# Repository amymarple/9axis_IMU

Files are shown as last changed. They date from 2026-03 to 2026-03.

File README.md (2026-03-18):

# 9-Axis IMU Intan Sync Toolbox

Author: Hongyu Chang
Date: 2026/03/01

This repository is organized as a small toolbox for collecting 9-axis IMU data with an Arduino Mega, sending a TTL sync pulse to an Intan system, and logging the IMU stream to a computer with Python.

The active toolbox now has one supported Arduino sketch and one supported Python logger:

- `arduino/imu_intan_sync_toolbox/imu_intan_sync_toolbox.ino`
- `python/read_imu.py`

Legacy experiments that are not part of the supported workflow are kept under `archive/`.

## Folder Layout

- `arduino/imu_intan_sync_toolbox/`
  Arduino sketch for the MPU9250 + Intan TTL sync workflow.
- `python/read_imu.py`
  Python logger that starts the Arduino stream, reads binary packets, and saves a CSV file.
- `python/requirements.txt`
  Python dependency list.
- `3D_printing_parts/`
  3D design files for mounting the IMU as part of an electrophysiology headstage assembly.
- `archive/`
  Older notebook, legacy Arduino sketches, legacy Python logger, and unrelated servo test material.

## Hardware

This toolbox assumes:

- Arduino Mega
- MPU9250 IMU
- Intan digital input for the sync pulse

Default wiring for the Arduino Mega:

- `MPU9250 VCC -> 3.3V`
- `MPU9250 GND -> GND`
- `MPU9250 SDA -> pin 20`
- `MPU9250 SCL -> pin 21`
- `Arduino pin 13 -> Intan digital input`
- `Arduino GND -> Intan GND`

Important:

- Verify your Intan digital input voltage compatibility before directly wiring the Arduino sync pin.
- Use a level shifter if your recording setup requires it.
- A shared ground between Arduino and Intan is required for reliable TTL synchronization.

Reference for the Arduino-side IMU implementation:

- based on `hideakitai/MPU9250`
- based on `arnefmeyer/IMUReaderPlugin`
- https://github.com/hideakitai/MPU9250.git
- https://github.com/arnefmeyer/IMUReaderPlugin.git

## 3D Printing Parts

The folder `3D_printing_parts/` contains the mechanical design files for incorporating the IMU into the ephys headstage setup.

Included files:

- `mouse_cam_base_final_withgyro_wall_2.5mm.stl`
- `mouse_cam_base_final_withgyro_wall.stl`
- `mouse_cam_base_final_withgyro_wall.ipt`
- `mouse_cam_base_final_withgyro-base_10deg.ipt`

File types:

- `.stl` files are ready for slicing and 3D printing.
- `.ipt` files are Autodesk Inventor part files for editing the design.

Design purpose:

- provide a base that incorporates the IMU into the headstage assembly
- support integration with the electrophysiology headstage hardware
- make the IMU mounting reproducible across experiments

Practical note:

- Use the `.stl` files for printing the current version.
- Use the `.ipt` files if you need to modify the geometry for a different headstage, cable routing, wall thickness, or sensor placement.

## Arduino Behavior

The sketch:

- reads the MPU9250 at a fixed target rate of `100 Hz`
- emits a `1 ms` TTL pulse on Arduino pin `13`
- sends one binary IMU packet for each sample
- includes `arduino_millis` and `sample_index` in every packet

The default packet fields are:

- `arduino_millis`
- `sample_index`
- `accel_x/y/z_g`
- `gyro_x/y/z_dps`
- `mag_x/y/z_mg`
- `roll/pitch/yaw_deg`
- `linear_accel_x/y/z_g`

Supported serial commands:

- `s` start streaming and reset the sample counter
- `x` stop streaming
- `p` send one test TTL pulse
- `i` print sketch information
- `c` run sensor calibration and print calibration values

## IMU Calibration

Before recording, you can calibrate the IMU by opening the serial monitor or a serial terminal and sending:

```text
c
```

During calibration, the Arduino sketch prints these instructions:

```text
# Accel/gyro calibration will start in 5 seconds.
# Keep the IMU still on a flat surface.
# Magnetometer calibration will start in 5 seconds.
# Move the IMU in a figure-eight pattern until complete.
```

Recommended calibration workflow:

- Place the IMU flat on a stable surface.
- Send the `c` command.
- Do not touch the IMU during the accelerometer and gyroscope calibration step.
- When prompted for magnetometer calibration, move the IMU through a broad figure-eight motion until the routine finishes.
- Save the printed calibration values if you want a record of that session.

## Setup

### 1. Arduino library

Install the `MPU9250` Arduino library by hideakitai in the Arduino IDE or Arduino CLI.

### 2. Python environment

Install Python dependencies:

```bash
pip install -r python/requirements.txt
```

### 3. Upload the Arduino sketch

Upload:

`arduino/imu_intan_sync_toolbox/imu_intan_sync_toolbox.ino`

## Logging Data

Example command on Windows:

```bash
python python/read_imu.py --port COM5 --output-dir data
```

Optional: stop automatically after a fixed duration:

```bash
python python/read_imu.py --port COM5 --output-dir data --duration-seconds 600
```

The logger will:

- open the serial port
- wait for the Arduino to reboot
- stop any old stream
- start a fresh stream
- align to the IMU packet header
- save data as CSV in the chosen output folder

The output CSV contains:

- computer receive time in UTC
- computer Unix time in seconds
- Arduino timestamp and sample index
- all IMU channels from the packet

## Synchronizing With Intan

For each IMU packet, the Arduino sends one TTL pulse on pin `13`. Record that digital input in Intan and align the Intan pulse train with the CSV `sample_index` and `arduino_millis` columns.

This gives you:

- a hardware sync event recorded by Intan
- the corresponding IMU sample number in the computer log

## Notes

- If you need a different sampling rate, edit `SAMPLE_RATE_HZ` in the Arduino sketch.
- If you need a different sync pin, edit `SYNC_PIN` in the Arduino sketch.
- The `archive/` folder is kept only for reference and is not part of the supported toolbox workflow.

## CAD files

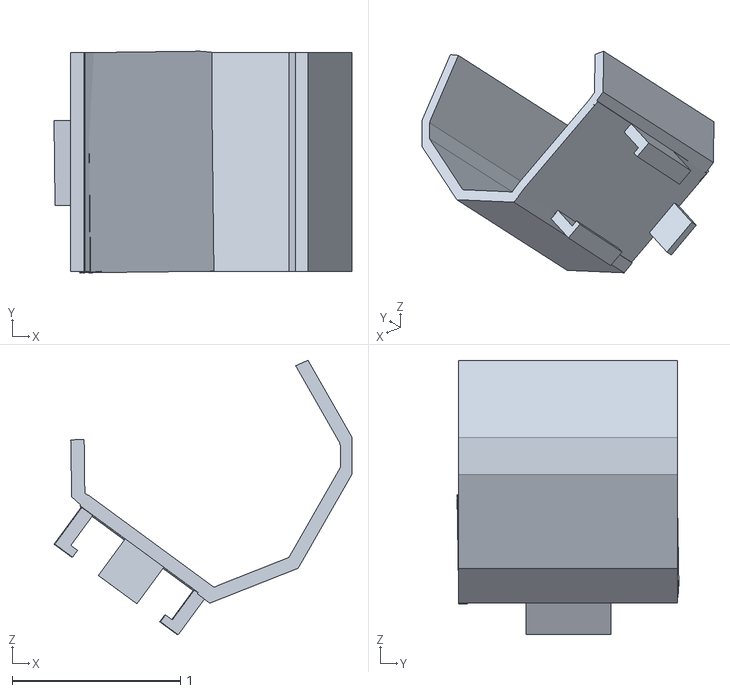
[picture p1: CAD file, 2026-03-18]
3D_printing_parts/mouse_cam_base_final_withgyro_wall.stl
1.77 x 1.32 x 1.63

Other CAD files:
3D_printing_parts/mouse_cam_base_final_withgyro_wall_2.5mm.stl
3D_printing_parts/mouse_cam_base_final_withgyro-base_10deg.ipt
3D_printing_parts/mouse_cam_base_final_withgyro_wall.ipt

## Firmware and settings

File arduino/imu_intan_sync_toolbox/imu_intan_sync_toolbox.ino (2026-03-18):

#include <Wire.h>
#include <MPU9250.h>

constexpr uint32_t BAUD_RATE = 115200;
constexpr uint16_t SAMPLE_RATE_HZ = 100;
constexpr uint32_t SAMPLE_INTERVAL_US = 1000000UL / SAMPLE_RATE_HZ;
constexpr uint16_t TTL_PULSE_US = 1000;
constexpr uint8_t SYNC_PIN = 13;
constexpr uint8_t IMU_I2C_ADDRESS = 0x68;
constexpr uint32_t PACKET_MAGIC = 0x31554D49UL;  // "IMU1"

struct __attribute__((packed)) ImuPacket {
  uint32_t magic;
  uint32_t arduino_millis;
  uint32_t sample_index;
  float accel_x_g;
  float accel_y_g;
  float accel_z_g;
  float gyro_x_dps;
  float gyro_y_dps;
  float gyro_z_dps;
  float mag_x_mg;
  float mag_y_mg;
  float mag_z_mg;
  float roll_deg;
  float pitch_deg;
  float yaw_deg;
  float linear_accel_x_g;
  float linear_accel_y_g;
  float linear_accel_z_g;
};

MPU9250 imu;
bool streaming = false;
uint32_t sample_index = 0;
unsigned long next_sample_due_us = 0;

void emitSyncPulse() {
  digitalWrite(SYNC_PIN, HIGH);
  delayMicroseconds(TTL_PULSE_US);
  digitalWrite(SYNC_PIN, LOW);
}

void printInfo() {
  Serial.println(F("# 9-axis IMU Intan sync toolbox"));
  Serial.print(F("# baud_rate="));
  Serial.println(BAUD_RATE);
  Serial.print(F("# sample_rate_hz="));
  Serial.println(SAMPLE_RATE_HZ);
  Serial.print(F("# sync_pin="));
  Serial.println(SYNC_PIN);
  Serial.println(F("# commands: s=start, x=stop, p=pulse, i=info, c=calibrate"));
}

void printCalibrationValues() {
  Serial.println(F("CALIBRATION_HEADER,accel_bias_x_mg,accel_bias_y_mg,accel_bias_z_mg,gyro_bias_x_dps,gyro_bias_y_dps,gyro_bias_z_dps,mag_bias_x_mg,mag_bias_y_mg,mag_bias_z_mg,mag_scale_x,mag_scale_y,mag_scale_z"));
  Serial.print(F("CALIBRATION_VALUES,"));
  Serial.print(imu.getAccBiasX() * 1000.0f / (float)MPU9250::CALIB_ACCEL_SENSITIVITY);
  Serial.print(',');
  Serial.print(imu.getAccBiasY() * 1000.0f / (float)MPU9250::CALIB_ACCEL_SENSITIVITY);
  Serial.print(',');
  Serial.print(imu.getAccBiasZ() * 1000.0f / (float)MPU9250::CALIB_ACCEL_SENSITIVITY);
  Serial.print(',');
  Serial.print(imu.getGyroBiasX() / (float)MPU9250::CALIB_GYRO_SENSITIVITY);
  Serial.print(',');
  Serial.print(imu.getGyroBiasY() / (float)MPU9250::CALIB_GYRO_SENSITIVITY);
  Serial.print(',');
  Serial.print(imu.getGyroBiasZ() / (float)MPU9250::CALIB_GYRO_SENSITIVITY);
  Serial.print(',');
  Serial.print(imu.getMagBiasX());
  Serial.print(',');
  Serial.print(imu.getMagBiasY());
  Serial.print(',');
  Serial.print(imu.getMagBiasZ());
  Serial.print(',');
  Serial.print(imu.getMagScaleX());
  Serial.print(',');
  Serial.print(imu.getMagScaleY());
  Serial.print(',');
  Serial.println(imu.getMagScaleZ());
}

void runCalibration() {
  streaming = false;
  Serial.println(F("# Accel/gyro calibration will start in 5 seconds."));
  Serial.println(F("# Keep the IMU still on a flat surface."));
  delay(5000);
  imu.verbose(true);
  imu.calibrateAccelGyro();

  Serial.println(F("# Magnetometer calibration will start in 5 seconds."));
  Serial.println(F("# Move the IMU in a figure-eight pattern until complete."));
  delay(5000);
  imu.calibrateMag();
  imu.verbose(false);
  printCalibrationValues();
}

void fillPacket(ImuPacket& packet) {
  packet.magic = PACKET_MAGIC;
  packet.arduino_millis = millis();
  packet.sample_index = sample_index;
  packet.accel_x_g = imu.getAccX();
  packet.accel_y_g = imu.getAccY();
  packet.accel_z_g = imu.getAccZ();
  packet.gyro_x_dps = imu.getGyroX();
  packet.gyro_y_dps = imu.getGyroY();
  packet.gyro_z_dps = imu.getGyroZ();
  packet.mag_x_mg = imu.getMagX();
  packet.mag_y_mg = imu.getMagY();
  packet.mag_z_mg = imu.getMagZ();
  packet.roll_deg = imu.getRoll();
  packet.pitch_deg = imu.getPitch();
  packet.yaw_deg = imu.getYaw();
  packet.linear_accel_x_g = imu.getLinearAccX();
  packet.linear_accel_y_g = imu.getLinearAccY();
  packet.linear_accel_z_g = imu.getLinearAccZ();
}

void sendPacket(const ImuPacket& packet) {
  emitSyncPulse();
  Serial.write(reinterpret_cast<const uint8_t*>(&packet), sizeof(packet));
}

void handleCommand(char command) {
  switch (command) {
    case 's':
      streaming = true;
      sample_index = 0;
      next_sample_due_us = micros();
      break;
    case 'x':
      streaming = false;
      break;
    case 'p':
      emitSyncPulse();
      break;
    case 'i':
      printInfo();
      break;
    case 'c':
      runCalibration();
      break;
    default:
      break;
  }
}

void setup() {
  pinMode(SYNC_PIN, OUTPUT);
  digitalWrite(SYNC_PIN, LOW);

  Serial.begin(BAUD_RATE);
  Wire.begin();
  delay(2000);

  if (!imu.setup(IMU_I2C_ADDRESS)) {
    while (true) {
      Serial.println(F("ERROR: MPU9250 connection failed. Check SDA/SCL, power, and address."));
      delay(2000);
    }
  }

  printInfo();
}

void loop() {
  while (Serial.available() > 0) {
    handleCommand((char)Serial.read());
  }

  const bool has_new_imu_data = imu.update();
  if (!streaming || !has_new_imu_data) {
    return;
  }

  const unsigned long now_us = micros();
  if ((long)(now_us - next_sample_due_us) < 0) {
    return;
  }

  ImuPacket packet;
  fillPacket(packet);
  sendPacket(packet);
  sample_index += 1;
  next_sample_due_us += SAMPLE_INTERVAL_US;

  if ((long)(now_us - next_sample_due_us) > (long)SAMPLE_INTERVAL_US) {
    next_sample_due_us = now_us + SAMPLE_INTERVAL_US;
  }
}

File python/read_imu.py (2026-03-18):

#!/usr/bin/env python3
"""Read binary IMU packets from Arduino and save them to CSV."""

from __future__ import annotations

import argparse
import csv
from datetime import datetime, timezone
from pathlib import Path
import struct
import sys
import time

import serial


PACKET_MAGIC = 0x31554D49
PACKET_MAGIC_BYTES = PACKET_MAGIC.to_bytes(4, byteorder="little")
PACKET_STRUCT = struct.Struct("<III15f")
CSV_HEADER = [
    "computer_time_utc",
    "computer_unix_time_s",
    "arduino_millis",
    "sample_index",
    "accel_x_g",
    "accel_y_g",
    "accel_z_g",
    "gyro_x_dps",
    "gyro_y_dps",
    "gyro_z_dps",
    "mag_x_mg",
    "mag_y_mg",
    "mag_z_mg",
    "roll_deg",
    "pitch_deg",
    "yaw_deg",
    "linear_accel_x_g",
    "linear_accel_y_g",
    "linear_accel_z_g",
]


def parse_args() -> argparse.Namespace:
    parser = argparse.ArgumentParser(
        description="Read IMU data from Arduino and save it to CSV."
    )
    parser.add_argument("--port", required=True, help="Serial port, for example COM5.")
    parser.add_argument(
        "--baudrate",
        type=int,
        default=115200,
        help="Serial baud rate. Must match the Arduino sketch.",
    )
    parser.add_argument(
        "--output-dir",
        type=Path,
        default=Path("data"),
        help="Directory where the CSV file will be saved.",
    )
    parser.add_argument(
        "--basename",
        default="imu_session",
        help="Prefix used for the CSV filename.",
    )
    parser.add_argument(
        "--duration-seconds",
        type=float,
        default=None,
        help="Optional maximum acquisition duration in seconds.",
    )
    parser.add_argument(
        "--timeout-seconds",
        type=float,
        default=2.0,
        help="Serial timeout in seconds.",
    )
    parser.add_argument(
        "--startup-delay-seconds",
        type=float,
        default=2.5,
        help="Delay after opening the serial port to allow Arduino reboot.",
    )
    parser.add_argument(
        "--print-every",
        type=int,
        default=100,
        help="Print one status update every N packets.",
    )
    parser.add_argument(
        "--flush-every",
        type=int,
        default=100,
        help="Flush the CSV file every N packets.",
    )
    return parser.parse_args()


def build_output_path(output_dir: Path, basename: str) -> Path:
    output_dir.mkdir(parents=True, exist_ok=True)
    timestamp = datetime.now(timezone.utc).strftime("%Y%m%d_%H%M%S")
    return output_dir / f"{basename}_{timestamp}.csv"


def send_command(ser: serial.Serial, command: str) -> None:
    ser.write(command.encode("ascii"))
    ser.flush()


def align_to_packet_header(ser: serial.Serial) -> bytes:
    window = bytearray()
    while True:
        byte = ser.read(1)
        if not byte:
            raise TimeoutError("Timed out while waiting for IMU packet header.")

        window += byte
        if len(window) > len(PACKET_MAGIC_BYTES):
            window = window[-len(PACKET_MAGIC_BYTES) :]

        if bytes(window) == PACKET_MAGIC_BYTES:
            remainder = ser.read(PACKET_STRUCT.size - len(PACKET_MAGIC_BYTES))
            if len(remainder) != PACKET_STRUCT.size - len(PACKET_MAGIC_BYTES):
                raise TimeoutError("Timed out while reading the rest of the IMU packet.")
            return PACKET_MAGIC_BYTES + remainder


def read_packet(ser: serial.Serial) -> tuple[object, ...]:
    packet = ser.read(PACKET_STRUCT.size)
    if len(packet) != PACKET_STRUCT.size:
        raise TimeoutError("Timed out while reading an IMU packet.")

    if packet[: len(PACKET_MAGIC_BYTES)] != PACKET_MAGIC_BYTES:
        packet = align_to_packet_header(ser)

    unpacked = PACKET_STRUCT.unpack(packet)
    if unpacked[0] != PACKET_MAGIC:
        raise ValueError("Corrupted packet: bad magic value.")
    return unpacked


def packet_to_row(packet: tuple[object, ...]) -> list[object]:
    now_utc = datetime.now(timezone.utc)
    return [
        now_utc.isoformat(),
        f"{now_utc.timestamp():.6f}",
        packet[1],
        packet[2],
        *packet[3:],
    ]


def main() -> int:
    args = parse_args()
    output_path = build_output_path(args.output_dir, args.basename)

    with serial.Serial(
        port=args.port,
        baudrate=args.baudrate,
        timeout=args.timeout_seconds,
    ) as ser, output_path.open("w", newline="", encoding="utf-8") as csv_file:
        writer = csv.writer(csv_file)
        writer.writerow(CSV_HEADER)

        time.sleep(args.startup_delay_seconds)
        ser.reset_input_buffer()
        ser.reset_output_buffer()

        send_command(ser, "x")
        time.sleep(0.1)
        ser.reset_input_buffer()
        send_command(ser, "s")

        packet_count = 0
        start_time = time.monotonic()
        first_packet = align_to_packet_header(ser)
        packet = PACKET_STRUCT.unpack(first_packet)
        writer.writerow(packet_to_row(packet))
        packet_count += 1

        print(f"Logging IMU data to {output_path}")
        try:
            while True:
                if (
                    args.duration_seconds is not None
                    and time.monotonic() - start_time >= args.duration_seconds
                ):
                    break

                packet = read_packet(ser)
                writer.writerow(packet_to_row(packet))
                packet_count += 1

                if packet_count % args.flush_every == 0:
                    csv_file.flush()

                if packet_count % args.print_every == 0:
                    elapsed = time.monotonic() - start_time
                    rate = packet_count / elapsed if elapsed > 0 else 0.0
                    print(
                        "packets="
                        f"{packet_count} sample_index={packet[2]} arduino_millis={packet[1]} "
                        f"rate={rate:.2f} Hz"
                    )
        except KeyboardInterrupt:
            print("Stopping acquisition on keyboard interrupt.")
        finally:
            send_command(ser, "x")
            csv_file.flush()

    print(f"Saved {packet_count} packets to {output_path}")
    return 0


if __name__ == "__main__":
    sys.exit(main())
